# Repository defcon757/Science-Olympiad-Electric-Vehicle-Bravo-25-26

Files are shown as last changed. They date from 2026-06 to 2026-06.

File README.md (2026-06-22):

# Arduino Mega EV Science Olympiad 2025-2026

Precision encoder-based electric vehicle platform for the Science Olympiad Electric Vehicle event.

This project uses an Arduino Mega 2560, TB6612FNG dual motor driver, DC gear motors with encoders, and a start button to drive an autonomous vehicle a commanded distance with repeatable stopping accuracy. Version 3.0 currently focuses on straight-line distance travel, encoder-based wheel balancing, active braking, trimming, and timed turns.

## Current Features

- Arduino Mega 2560 control
- TB6612FNG dual motor driver support
- Encoder interrupt counting on both drive motors
- Closed-loop straight-line balancing using encoder speed feedback
- Distance-based movement in millimeters
- Early-stop plus low-speed trim phase for improved accuracy
- Balanced active braking
- Button-triggered autonomous run sequence
- Serial Monitor diagnostics

## Hardware

| Component | Model / Notes |
| --- | --- |
| Microcontroller | Arduino Mega 2560 |
| Motor driver | TB6612FNG dual H-bridge |
| Motors | Two DC gear motors with encoders |
| Display | Optional SH1106 128x64 I2C OLED |
| Input | Momentary push button |
| Power | External motor battery supply with common ground |

## Version 3.0 Pin Mapping

| Signal | Arduino Mega Pin |
| --- | --- |
| Motor A IN1 | D5 |
| Motor A IN2 | D6 |
| Motor A ENA / PWM | D7 |
| Motor B IN3 | D8 |
| Motor B IN4 | D9 |
| Motor B ENB / PWM | D10 |
| Start Button | D27 to GND |
| Encoder A interrupt | D2 |
| Encoder B interrupt | D18 |

Older development notes used D13 for the start button and documented both encoder channels per wheel. The current working Version 3.0 sketch uses D27 for the start button and counts one interrupt signal from each motor.

## Mechanical Calibration

Current Version 3.0 constants:

```cpp
const float stepsPerRotation = 215.0;
const float mmPerRotation = 223.05;
const float stepsPerMM = stepsPerRotation / mmPerRotation;
```

These values should be recalibrated whenever wheel diameter, tire grip, battery voltage, motor gearing, or vehicle mass changes.

## Repository Layout

```text
.
|-- src/
|   `-- EV_Science_Olympiad_V3.ino
|-- examples/
|   |-- button_test/
|   |-- motor_test/
|   `-- oled_test/
|-- docs/
|   |-- calibration.md
|   |-- hardware.md
|   `-- roadmap.md
|-- .gitignore
|-- LICENSE
`-- README.md
```

## Uploading

1. Open `src/EV_Science_Olympiad_V3.ino` in the Arduino IDE.
2. Select `Arduino Mega or Mega 2560`.
3. Select the correct serial port.
4. Upload the sketch.
5. Open Serial Monitor at `115200` baud.
6. Press the start button to run the programmed movement sequence.

## Default Movement Sequence

The Version 3.0 sketch currently runs:

```cpp
moveDistanceMM(3900);
delay(1000);
turnRight(850);
delay(1000);
moveDistanceMM(500);
```

This was noted as working for a 4.3 meter target path. Adjust the distances and turn duration for each event setup.

## Development Roadmap

- Recheck encoder counts per wheel rotation
- Tune `undershootPercent`, trim speed, and braking time
- Add OLED status screens
- Replace timed turns with encoder-based turns
- Add a true trapezoidal velocity profile
- Add PID straight-line correction
- Build obstacle navigation around the center can

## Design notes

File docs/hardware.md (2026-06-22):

# Hardware Notes

## Core Parts

- Arduino Mega 2560
- TB6612FNG dual motor driver
- Two DC gear motors with encoders
- Momentary start button
- External motor battery supply
- Optional SH1106 128x64 I2C OLED display

## Motor Driver Wiring

| TB6612FNG Pin | Arduino Mega Pin | Purpose |
| --- | --- | --- |
| IN1 | D5 | Motor A direction |
| IN2 | D6 | Motor A direction |
| ENA | D7 | Motor A PWM |
| IN3 | D8 | Motor B direction |
| IN4 | D9 | Motor B direction |
| ENB | D10 | Motor B PWM |
| VCC | 5V | Logic power |
| VM | Battery positive | Motor power |
| GND | Common ground | Shared reference |

The current motor driver board does not expose a separate STBY pin.

## Start Button

Version 3.0 uses:

| Button Side | Connection |
| --- | --- |
| Signal | D27 |
| Other side | GND |

The sketch uses `INPUT_PULLUP`, so the logic is:

```text
LOW  = pressed
HIGH = released
```

## Encoder Wiring

Version 3.0 counts one interrupt channel from each motor:

| Encoder Signal | Arduino Mega Pin |
| --- | --- |
| Motor A encoder | D2 |
| Motor B encoder | D18 |

Earlier notes used full quadrature wiring:

| Encoder Signal | Arduino Mega Pin |
| --- | --- |
| Left A | D2 |
| Left B | D3 |
| Right A | D18 |
| Right B | D19 |

Full quadrature support is a good future upgrade because it allows direction-aware counting.

## Optional OLED Wiring

| OLED Pin | Arduino Mega Pin |
| --- | --- |
| VCC | 5V |
| GND | GND |
| SDA | D20 |
| SCL | D21 |

Recommended libraries:

```cpp
#include <Wire.h>
#include <Adafruit_GFX.h>
#include <Adafruit_SH110X.h>
```

Display object:

```cpp
Adafruit_SH1106G display(128, 64, &Wire, -1);
```

Common I2C address:

```cpp
0x3C
```

## Power Notes

Motor current spikes can reset the Arduino or corrupt the OLED display. Use:

- Separate motor and logic power when possible
- Common ground between Arduino and motor driver
- A bulk capacitor across motor supply and ground

Suggested capacitor:

```text
470 uF to 1000 uF
```

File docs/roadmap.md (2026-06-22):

# Development Roadmap

## Completed

- Arduino Mega 2560 hardware platform
- TB6612FNG motor driver wiring
- Start button trigger
- Encoder interrupt counting
- Distance calculation
- Straight-line movement routine
- Early-stop and trim movement strategy
- Active braking
- Timed right and left turn helpers

## In Progress

- Encoder calibration
- Straight-line tuning
- Stop accuracy tuning
- Turn duration tuning

## Next Improvements

### OLED Interface

Display:

```text
State
Left encoder
Right encoder
Target steps
Target distance
Distance traveled
```

### Full Quadrature Encoder Support

Use both A and B encoder channels per motor so the robot can count forward and reverse motion.

### Encoder-Based Turns

Replace:

```cpp
turnRight(850);
```

with:

```cpp
turnRightDegrees(90);
```

### Trapezoidal Velocity Profile

Future movement profile:

```text
Accelerate
Cruise
Decelerate
Trim
Stop
```

Expected benefits:

- Less wheel slip
- Better repeatability
- More predictable stopping

### PID Straight-Line Correction

Use encoder difference to adjust left and right motor PWM continuously.

### Obstacle Navigation

Event goal:

```text
Drive forward
Navigate around center obstacle
Return to centerline
Stop at target
```

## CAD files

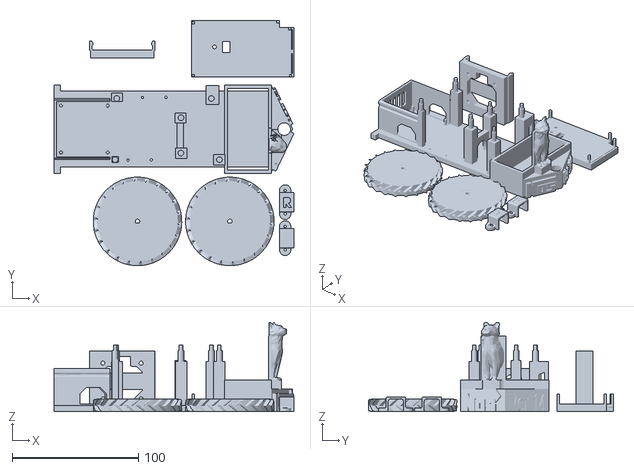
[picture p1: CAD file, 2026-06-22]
Eletric Vehicle.stl
189.8 x 194.0 x 70.6

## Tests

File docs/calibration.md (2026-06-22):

# Calibration Guide

Accurate distance travel depends on measuring the actual relationship between encoder counts and vehicle movement.

## Current Version 3.0 Values

```cpp
const float stepsPerRotation = 215.0;
const float mmPerRotation = 223.05;
const float stepsPerMM = stepsPerRotation / mmPerRotation;
```

This means:

```text
215 encoder counts = 1 wheel rotation
1 wheel rotation = 223.05 mm of travel
```

## Recalibrating Encoder Counts

1. Mark the wheel with tape.
2. Rotate the wheel exactly one full revolution.
3. Read the encoder count from Serial Monitor.
4. Repeat at least five times.
5. Average the counts.
6. Update `stepsPerRotation`.

## Recalibrating Distance Per Rotation

1. Mark the floor and wheel start point.
2. Roll the vehicle forward for 5 to 10 wheel rotations.
3. Measure total distance traveled.
4. Divide by the number of rotations.
5. Update `mmPerRotation`.

Example:

```text
Measured distance: 1115.25 mm
Wheel rotations: 5

mmPerRotation = 1115.25 / 5
mmPerRotation = 223.05
```

## Distance Formula

```cpp
targetSteps = distanceMM * stepsPerMM;
```

where:

```cpp
stepsPerMM = stepsPerRotation / mmPerRotation;
```

## Tuning Stop Accuracy

The current sketch uses an early-stop point and then trims slowly:

```cpp
const float undershootPercent = 0.75;
```

If the vehicle stops too short, increase this value. If it overshoots before trim, decrease it.

Tune in this order:

1. `stepsPerRotation`
2. `mmPerRotation`
3. `moveMinPWM` and `moveMaxPWM`
4. active brake duration
5. `undershootPercent`
6. trim PWM
7. steering trim

## Test Log Template

```text
Date:
Battery voltage:
Target distance:
Actual distance:
Error:
Surface:
stepsPerRotation:
mmPerRotation:
undershootPercent:
moveMinPWM:
moveMaxPWM:
trimMinPWM:
trimMaxPWM:
Notes:
```

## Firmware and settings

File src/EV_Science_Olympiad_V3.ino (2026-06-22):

#include <Arduino.h>

/* ================= MOTOR PINS ================= */
const int IN1 = 5;
const int IN2 = 6;
const int ENA = 7;

const int IN3 = 8;
const int IN4 = 9;
const int ENB = 10;

/* ================= START BUTTON ================= */
const int START_BUTTON = 27;   // Button between D27 and GND

/* ================= ENCODER PINS ================= */
const int ENC_A = 2;
const int ENC_B = 18;

volatile long encoderCountA = 0;
volatile long encoderCountB = 0;

/* ================= MECHANICAL PARAMETERS ================= */
const float stepsPerRotation = 215.0;
const float mmPerRotation = 223.05;
const float stepsPerMM = stepsPerRotation / mmPerRotation;

/* ================= SPEED SETTINGS ================= */
const int moveMinPWM = 60;
const int moveMaxPWM = 120;

const int turnPWM = 120;

const int trimMinPWM = 50;
const int trimMaxPWM = 80;

const float undershootPercent = 0.75;

float steeringTrim = 0.0;

/* ================= ENCODER ISRS ================= */
void ISR_encoderA() { encoderCountA++; }
void ISR_encoderB() { encoderCountB++; }

/* ================= MOTOR CONTROL ================= */
void coastMotors();
void brakeMotors();

void turnLeft(unsigned long durationMs) {
  Serial.print("[");
  Serial.print(millis());
  Serial.println(" ms] Turning LEFT");

  analogWrite(ENB, 0);
  digitalWrite(IN3, LOW);
  digitalWrite(IN4, LOW);

  digitalWrite(IN1, HIGH);
  digitalWrite(IN2, LOW);
  analogWrite(ENA, turnPWM);

  delay(durationMs);

  brakeMotors();
  delay(100);
  coastMotors();

  Serial.print("[");
  Serial.print(millis());
  Serial.println(" ms] Left turn complete");
}

void turnRight(unsigned long durationMs) {
  Serial.print("[");
  Serial.print(millis());
  Serial.println(" ms] Turning RIGHT");

  analogWrite(ENA, 0);
  digitalWrite(IN1, LOW);
  digitalWrite(IN2, LOW);

  digitalWrite(IN3, HIGH);
  digitalWrite(IN4, LOW);
  analogWrite(ENB, turnPWM);

  delay(durationMs);

  brakeMotors();
  delay(100);
  coastMotors();

  Serial.print("[");
  Serial.print(millis());
  Serial.println(" ms] Right turn complete");
}

/* ================= DRIVE FORWARD WITH BALANCING ================= */
void driveForwardBalanced(int basePWM) {
  static long lastCountA = 0;
  static long lastCountB = 0;
  static unsigned long lastTime = 0;

  long currentA, currentB;
  unsigned long currentTime = millis();

  noInterrupts();
  currentA = encoderCountA;
  currentB = encoderCountB;
  interrupts();

  long deltaA = currentA - lastCountA;
  long deltaB = currentB - lastCountB;

  unsigned long deltaTime = currentTime - lastTime;
  if (deltaTime == 0) deltaTime = 1;

  float speedA = (deltaA * 1000.0) / deltaTime;
  float speedB = (deltaB * 1000.0) / deltaTime;

  lastCountA = currentA;
  lastCountB = currentB;
  lastTime = currentTime;

  float speedError = speedA - speedB;
  speedError -= steeringTrim;

  float Kp = 0.05;
  int correction = (int)(Kp * speedError);

  int pwmA = basePWM - correction;
  int pwmB = basePWM + correction;

  pwmA = constrain(pwmA, moveMinPWM, moveMaxPWM);
  pwmB = constrain(pwmB, moveMinPWM, moveMaxPWM);

  digitalWrite(IN1, HIGH);
  digitalWrite(IN2, LOW);
  analogWrite(ENA, pwmA);

  digitalWrite(IN3, HIGH);
  digitalWrite(IN4, LOW);
  analogWrite(ENB, pwmB);

  Serial.print("SpeedA: ");
  Serial.print(speedA);
  Serial.print(" cps | SpeedB: ");
  Serial.print(speedB);
  Serial.print(" cps | PWM A: ");
  Serial.print(pwmA);
  Serial.print(" | PWM B: ");
  Serial.println(pwmB);
}

/* ================= ACTIVE BRAKE WITH REVERSE ================= */
void brakeMotors() {
  Serial.print("[");
  Serial.print(millis());
  Serial.println(" ms] Applying balanced active brake...");

  static long lastCountA = 0;
  static long lastCountB = 0;
  static unsigned long lastTime = 0;

  lastTime = millis();
  unsigned long brakeStart = millis();

  while (millis() - brakeStart < 120) {
    long currentA, currentB;
    unsigned long currentTime = millis();

    noInterrupts();
    currentA = encoderCountA;
    currentB = encoderCountB;
    interrupts();

    long deltaA = currentA - lastCountA;
    long deltaB = currentB - lastCountB;

    unsigned long deltaTime = currentTime - lastTime;
    if (deltaTime == 0) deltaTime = 1;

    float speedA = (deltaA * 1000.0) / deltaTime;
    float speedB = (deltaB * 1000.0) / deltaTime;

    lastCountA = currentA;
    lastCountB = currentB;
    lastTime = currentTime;

    float speedError = speedA - speedB;

    float KpBrake = 0.08;
    int correction = (int)(KpBrake * speedError);

    int brakeA = 140 - correction;
    int brakeB = 140 + correction;

    brakeA = constrain(brakeA, 80, 200);
    brakeB = constrain(brakeB, 80, 200);

    digitalWrite(IN1, LOW);
    digitalWrite(IN2, HIGH);
    analogWrite(ENA, brakeA);

    digitalWrite(IN3, LOW);
    digitalWrite(IN4, HIGH);
    analogWrite(ENB, brakeB);
  }

  coastMotors();

  Serial.print("[");
  Serial.print(millis());
  Serial.println(" ms] Balanced brake complete.");
}

void coastMotors() {
  analogWrite(ENA, 0);
  analogWrite(ENB, 0);

  digitalWrite(IN1, LOW);
  digitalWrite(IN2, LOW);
  digitalWrite(IN3, LOW);
  digitalWrite(IN4, LOW);
}

/* ================= WAIT FOR COMPLETE STOP ================= */
void waitForCompleteStop(unsigned long stableTimeMs) {
  Serial.println("Verifying complete stop...");

  long lastA, lastB;
  noInterrupts();
  lastA = encoderCountA;
  lastB = encoderCountB;
  interrupts();

  unsigned long stableStart = millis();

  while (true) {
    long currentA, currentB;
    noInterrupts();
    currentA = encoderCountA;
    currentB = encoderCountB;
    interrupts();

    if (currentA != lastA || currentB != lastB) {
      stableStart = millis();
      lastA = currentA;
      lastB = currentB;
    }

    if (millis() - stableStart >= stableTimeMs) break;
    delay(10);
  }

  Serial.println("Confirmed: Robot fully stopped.");
}

/* ================= MOVE DISTANCE ================= */
void moveDistanceMM(float distanceMM) {
  long finalTarget = lround(distanceMM * stepsPerMM);
  long earlyStopTarget = finalTarget * undershootPercent;

  Serial.println("================================");
  Serial.print("Requested Distance (mm): ");
  Serial.println(distanceMM);
  Serial.print("Calculated Steps: ");
  Serial.println(finalTarget);
  Serial.print("Early Stop Steps: ");
  Serial.println(earlyStopTarget);
  Serial.println("================================");

  noInterrupts();
  encoderCountA = 0;
  encoderCountB = 0;
  interrupts();

  bool mainStopped = false;
  bool trimming = false;
  bool complete = false;
  int currentPWM = moveMinPWM;

  unsigned long lastPrint = 0;

  while (!complete) {
    long countA, countB;
    noInterrupts();
    countA = encoderCountA;
    countB = encoderCountB;
    interrupts();

    long progress = max(countA, countB);

    if (!mainStopped) {
      currentPWM += 1;
      currentPWM = constrain(currentPWM, moveMinPWM, moveMaxPWM);

      driveForwardBalanced(currentPWM);

      if (progress >= earlyStopTarget) {
        Serial.print("[");
        Serial.print(millis());
        Serial.println(" ms] Early stop reached.");

        brakeMotors();
        delay(150);
        coastMotors();

        mainStopped = true;
        waitForCompleteStop(3000);

        trimming = true;
        Serial.println("Starting trim phase...");
      }
    }

    if (trimming && !complete) {
      if (progress < finalTarget) {
        int trimPWM = constrain(trimMinPWM, trimMinPWM, trimMaxPWM);
        driveForwardBalanced(trimPWM);
      } else {
        brakeMotors();
        delay(100);
        coastMotors();

        trimming = false;
        complete = true;

        Serial.print("[");
        Serial.print(millis());
        Serial.println(" ms] Final target reached.");
      }
    }

    if (millis() - lastPrint >= 100) {
      Serial.print("[");
      Serial.print(millis());
      Serial.print(" ms] ");
      Serial.print("Avg Steps: ");
      Serial.print(progress);
      Serial.print(" / ");
      Serial.println(finalTarget);
      lastPrint = millis();
    }
  }
}

/* ================= SETUP ================= */
void setup() {
  Serial.begin(115200);

  pinMode(IN1, OUTPUT);
  pinMode(IN2, OUTPUT);
  pinMode(ENA, OUTPUT);

  pinMode(IN3, OUTPUT);
  pinMode(IN4, OUTPUT);
  pinMode(ENB, OUTPUT);

  pinMode(START_BUTTON, INPUT_PULLUP);

  pinMode(ENC_A, INPUT_PULLUP);
  pinMode(ENC_B, INPUT_PULLUP);

  attachInterrupt(digitalPinToInterrupt(ENC_A), ISR_encoderA, RISING);
  attachInterrupt(digitalPinToInterrupt(ENC_B), ISR_encoderB, RISING);

  Serial.println("Distance-Based Movement System Ready");

  delay(1000);
}

/* ================= LOOP ================= */
void loop() {
  static bool lastButtonState = HIGH;
  bool currentButtonState = digitalRead(START_BUTTON);

  if (lastButtonState == HIGH && currentButtonState == LOW) {
    Serial.println("Button pressed. Starting movement...");
    delay(50);

    moveDistanceMM(3900);

    delay(1000);

    turnRight(850);

    delay(1000);

    moveDistanceMM(500);
  }

  lastButtonState = currentButtonState;
}

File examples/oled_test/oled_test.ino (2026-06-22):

#include <Wire.h>
#include <Adafruit_GFX.h>
#include <Adafruit_SH110X.h>

Adafruit_SH1106G display(128, 64, &Wire, -1);

void setup() {
  Wire.begin();
  delay(200);

  display.begin(0x3C, true);
  display.clearDisplay();
  display.setTextSize(1);
  display.setTextColor(SH110X_WHITE);
  display.setCursor(0, 0);
  display.println("OLED Test");
  display.println("SH1106 ready");
  display.display();
}

void loop() {
}
